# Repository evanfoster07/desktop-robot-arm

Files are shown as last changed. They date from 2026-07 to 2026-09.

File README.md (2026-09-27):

# Desktop Robot Arm

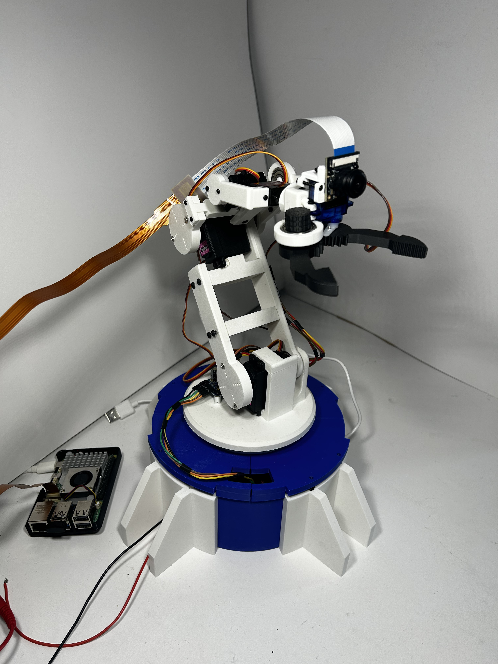
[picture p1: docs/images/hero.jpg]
Desktop Robot Arm


A 3D-printed desktop robot arm built from scratch, integrating robotics, embedded control, kinematics, and computer vision.

The arm is controlled by an ESP32 and uses a Raspberry Pi 5 with an eye-in-hand camera for computer vision. It combines custom motion control, forward/inverse kinematics, a custom-trained YOLO object detector, and closed-loop visual servoing to autonomously detect, approach, grasp, and place objects.

> Status: Object detection and arm control are integrated and working together to carry out autonomous pick-and-place tasks.

## Demo

Robot Arm Demo

*Autonomous pick-and-place demo with the robot’s POV shown above*

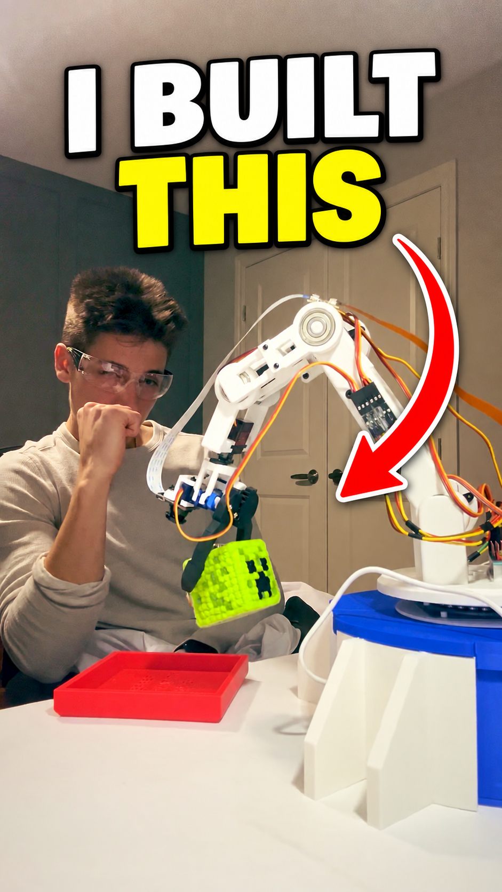
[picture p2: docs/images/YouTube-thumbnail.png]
Watch the full demo (https://youtube.com/shorts/6LVfA6hSM14?si=9LW-p4Ngw13JaFhd)


▶️ [Watch the full YouTube demo](https://youtube.com/shorts/6LVfA6hSM14?si=9LW-p4Ngw13JaFhd)

## Features

* Fully custom mechanical design in Fusion 360
* 3D-printed arm and gripper
* 5 controlled joints + gripper
* NEMA 17 stepper-driven base with TMC2209 control
* PCA9685-based servo control
* ESP32-based motion control
* Forward and inverse kinematics
* Cartesian end-effector positioning
* Non-blocking multi-joint servo motion
* Safe joint-angle limits and servo calibration
* Raspberry Pi 5 high-level control and computer vision
* Eye-in-hand IMX219 camera
* Custom YOLO object detection model
* Custom dataset captured from the robot's camera
* Raspberry Pi ↔ ESP32 serial communication
* Camera-space to robot-space coordinate transformation
* Closed-loop visual servoing with tunable Cartesian correction gains
* Autonomous target centering and approach
* Pitch retry logic for unreachable or unsuitable Cartesian poses
* Autonomous motion sequencing for grasping, goal alignment, placement, and return-home behavior
* Fully autonomous vision-guided pick and place

## Hardware

* ESP32 dev board
* Raspberry Pi 5 (8 GB)
* PCA9685 servo driver
* TMC2209 stepper motor driver
* NEMA 17 stepper motor
* MG996R servo x2
* 21G servo
* MG90S micro servo
* SG90 micro servo
* IMX219 camera
* 6V servo & stepper power supply
* Lazy Susan bearing
* 608 ball bearing x3
* Custom 3D-printed mechanical components
* Various fasteners and mounting hardware

## Mechanical Design

The arm was designed from scratch in Fusion 360 and went through a few iterations as I built and tested it.

The printable mechanical parts are available in [`main.3mf`](hardware/cad/main.3mf).

The base is driven by a NEMA 17 stepper motor, while the shoulder, elbow, wrist, and gripper are servo-driven. The final arm has control over:

1. Base rotation
2. Shoulder pitch
3. Elbow pitch
4. Wrist pitch
5. Wrist roll
6. Gripper

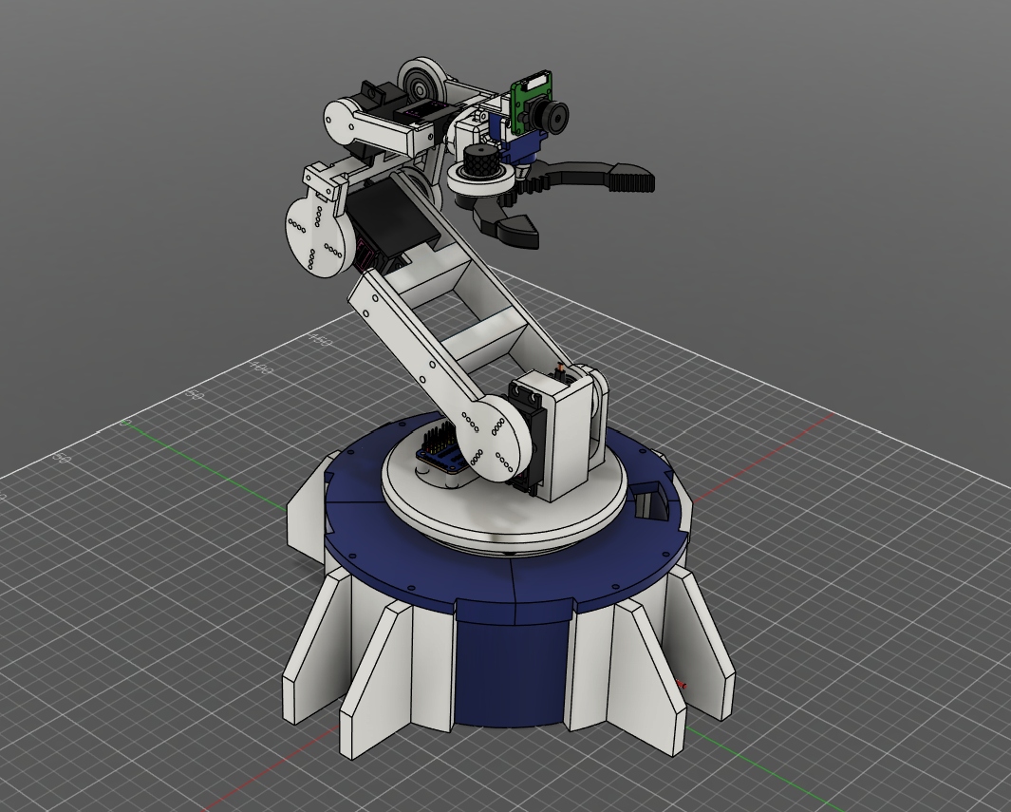
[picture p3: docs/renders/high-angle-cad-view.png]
High Angle CAD View


*High-angle CAD view of the complete robot arm assembly.*

A lot of the mechanical design ended up being driven by problems found during testing. For example, an early version of the base coupling had rotational slip, so I redesigned it with a tapered D-bore and external taper to improve repeatability. There was another issue where the wrist pitch servo screw did not adequately support the rest of the arm, so I designed a custom bracket to secure it in place.

Custom components include:

* Base and rotating platform
* Upper arm and forearm
* Wrist assembly
* Gripper
* Servo mounts
* Camera mount
* Electronics mounting components

## Electronics

The electronics are split between the ESP32 motion control system and the Raspberry Pi vision system.

The ESP32 controls the servos through the PCA9685 over I²C and configures the TMC2209 stepper driver over UART.

The main electronics include:

* ESP32 for real-time arm control
* PCA9685 for servo PWM control
* TMC2209 for NEMA 17 stepper control
* Dedicated 6V supply for the servos
* Raspberry Pi 5 for computer vision and high-level control
* IMX219 camera mounted to the arm

The system intentionally separates high-level perception and sequencing from low-level actuator control. The Raspberry Pi handles vision and task logic, while the ESP32 handles deterministic joint motion, calibration, and kinematics. 

- Raspberry Pi 5 communicates with the ESP32 over USB serial
- ESP32 receives Cartesian and joint commands
- ESP32 exposes current arm pose/state back to the Pi

The TMC2209 is configured through UART, allowing settings such as motor current and microstepping to be controlled in software.

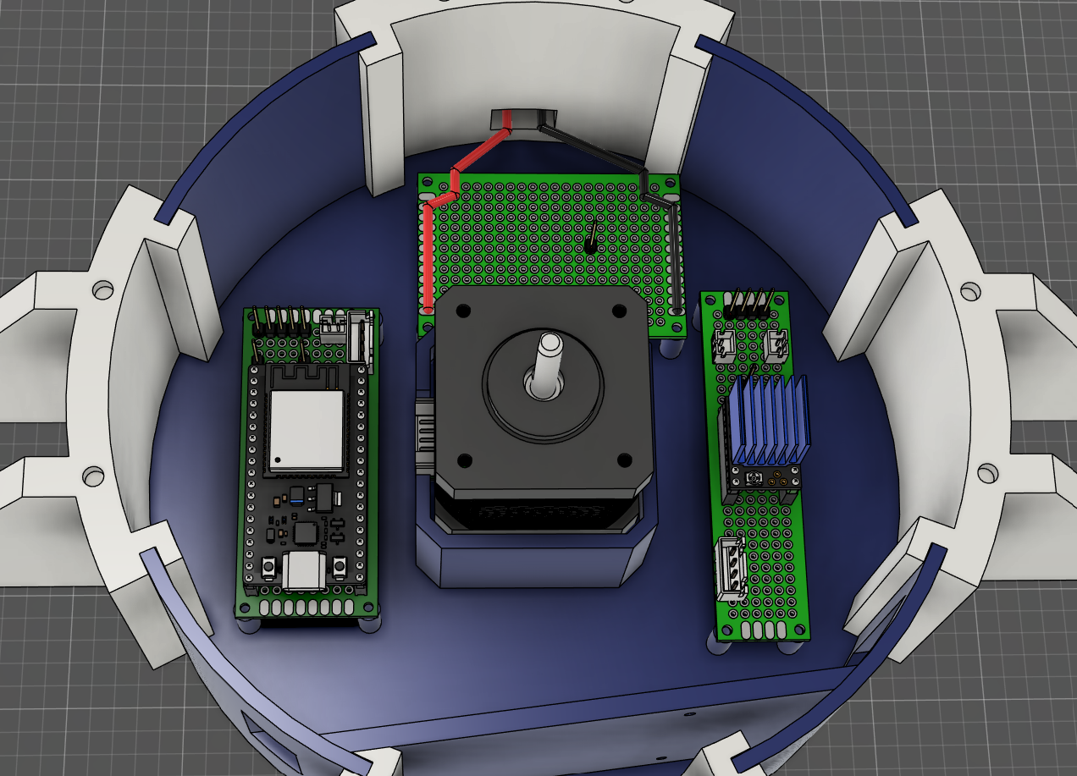
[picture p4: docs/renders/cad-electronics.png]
Base Electronics CAD


*CAD view of the electronics layout inside the robot arm base.*

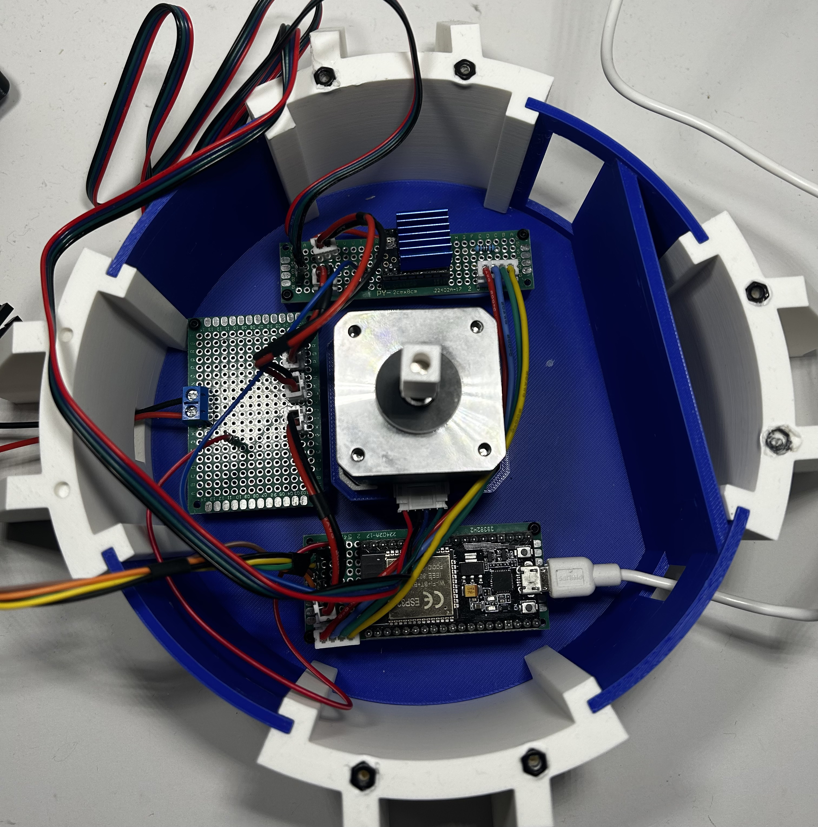
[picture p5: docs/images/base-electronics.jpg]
Base Electronics


*Final electronics implementation inside the robot base.*

The KiCad schematic and project files are available in [`kicad`](hardware/kicad/).

## Control System

The Raspberry Pi handles computer vision and higher-level decision making, while the ESP32 handles the actual motion of the arm.

The ESP32 firmware handles:

* Servo and stepper control
* Joint calibration
* Forward kinematics
* Inverse kinematics
* Cartesian pose commands
* Smooth multi-joint movement
* Safe joint limits
* Pose validation/rejection
* Servo pulse calibration
* Robot-state reporting over serial
* Joint-space and Cartesian command interfaces

### Motion Control

The arm can be controlled using either individual joint angles or Cartesian end-effector poses.

Forward kinematics calculate the end-effector position from the current joint angles, while inverse kinematics calculate the required joint angles for a desired position and orientation.

A calibration layer converts the mathematical joint angles into the actual servo coordinate system and accounts for servo direction, offsets, and mechanical limits.

Servo motion is also interpolated without blocking the main control loop, allowing multiple joints to move smoothly at the same time.

### Safety & Calibration

Each actuator has individually calibrated pulse-width and angular limits to prevent commands from driving the arm beyond its physical range. Cartesian poses are validated before execution, and the mapping layer converts mathematical joint angles into the physical coordinate system of each servo.

Custom classes were created for servo and stepper control, FK/IK, joint mapping, and higher-level robot arm control.

## Computer Vision

Computer vision runs on the Raspberry Pi 5 using an IMX219 camera mounted directly to the arm.

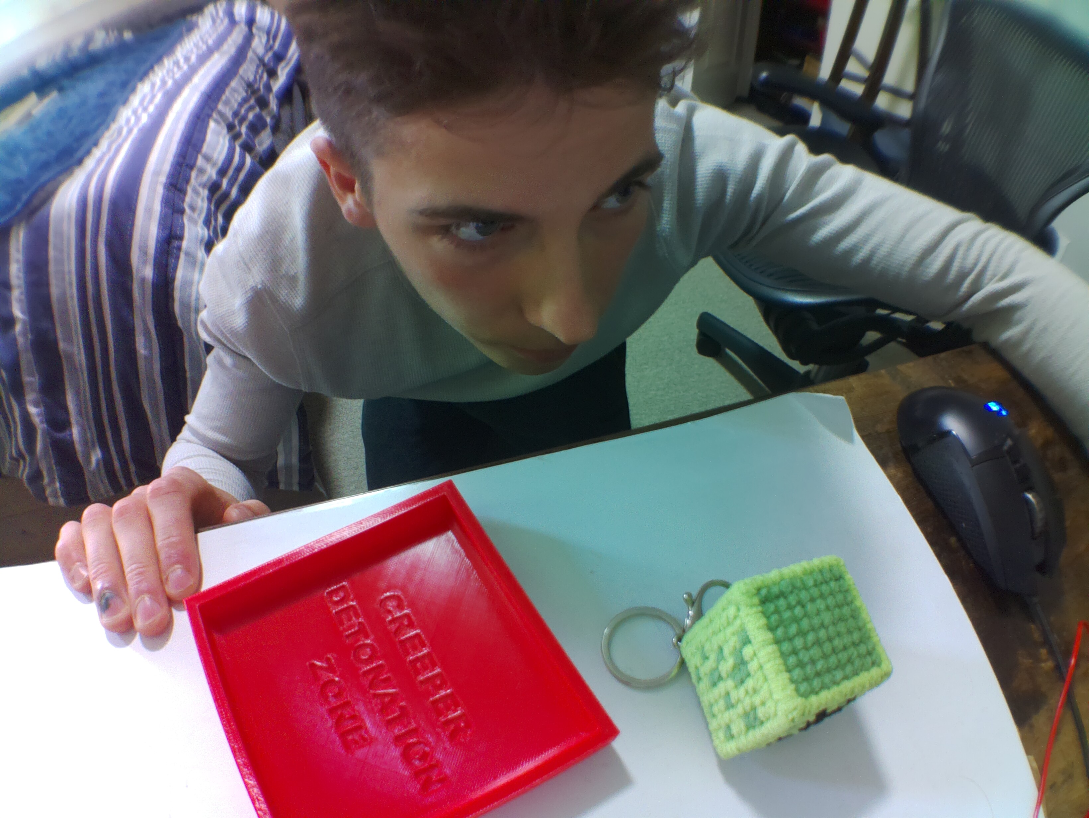
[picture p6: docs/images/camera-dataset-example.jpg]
Camera Dataset Example


*Example training image captured from the arm's eye-in-hand camera.*

I initially experimented with OpenCV ORB feature matching, but it wasn't reliable enough across different viewpoints. I then moved to a learned object detection approach using Ultralytics YOLO.

The current model is trained on a custom dataset of 625 images collected from the robot's own camera.

The training process includes:

* Custom Python dataset capture scripts using the eye-in-hand camera
* Annotation conversion tooling
* Transfer learning from pretrained YOLO weights
* Manual training-parameter tuning, including layer freezing and training duration
* Custom multi-class detection for the Creeper and goal
* Deployment to the Raspberry Pi for live inference

Training was performed using transfer learning rather than training a detector from scratch. I experimented with layer freezing, epoch count, batch size, and train/validation splits to balance training time and model performance before deploying the resulting weights to the Raspberry Pi.

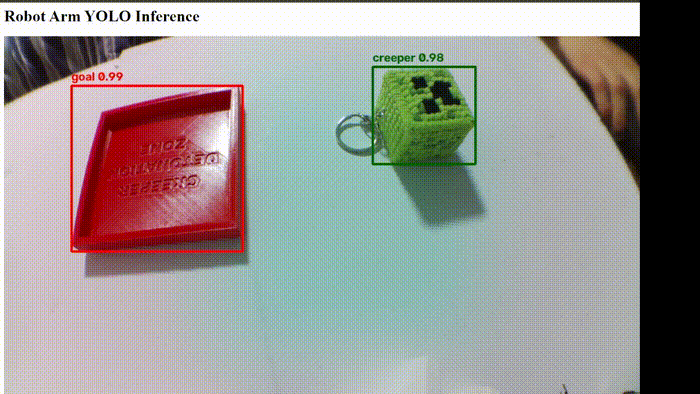
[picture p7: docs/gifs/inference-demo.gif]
YOLO Inference Demo


*Example inference using the custom-trained YOLO model.*

## Visual Servoing & Autonomous Pick and Place

Instead of relying on a precisely calibrated external camera or a single position estimate, I chose an eye-in-hand visual-servoing approach. This allowed me to use a low-cost camera mounted directly to the arm and continuously correct the robot's position using live image feedback.

The visual servoing process is:

1. Detect Creeper using the YOLO model
2. Calculate bounding-box error relative to the desired camera target
3. Normalize image-space error
4. Apply tunable Cartesian gains
5. Transform the correction from camera coordinates into the robot coordinate frame
6. Request the current Cartesian arm pose from the ESP32
7. Send the corrected Cartesian pose
8. Repeat until the target is centered
9. Execute autonomous approach and grasp
10. Return to start pose
11. Detect and center on the goal
12. Move to placement pose and release
13. Return home

Because some desired Cartesian corrections could produce unreachable or mechanically unsafe configurations, the high-level motion sequence includes retry logic that adjusts the end-effector pitch before attempting the pose again.

## Software

* C++ - ESP32 firmware, actuator control, calibration, forward/inverse kinematics, Cartesian motion, and safety limits
* Python - computer vision, YOLO training, visual servoing, motion sequencing, serial communication, dataset tools, and web interface
* Fusion 360 - mechanical design
* OpenCV - image processing and early CV experiments
* Ultralytics YOLO - object detection
* AccelStepper / TMCStepper - stepper control
* Adafruit PCA9685 - servo control

## Design Files

Project design files are included in the repository:

- [`hardware/cad/main.3mf`](hardware/cad/main.3mf) - 3D-printable robot arm parts
- [`hardware/kicad/`](hardware/kicad/) - KiCad schematic/project files for the robot electronics

## Development Process

The project has been developed and tested incrementally:

* Mechanical design and actuator integration
* Servo and stepper calibration
* Non-blocking motion control
* FK/IK and Cartesian control
* Raspberry Pi camera integration
* Custom YOLO dataset and training pipeline
* Pi ↔ ESP32 serial protocol
* Closed-loop visual servoing
* Autonomous motion sequencing
* Successful autonomous pick-and-place

## Challenges & Lessons Learned

* Mechanical repeatability:

  * Initial base coupling had significant rotational slip
  * Redesigned the coupling using a tapered D-bore and external taper
  * Added a custom wrist pitch bracket after identifying excessive movement around the servo mounting point

* Stepper control:

  * Configured the TMC2209 through UART
  * Tuned motor current, microstepping, speed, and acceleration
  * Debugged hardware and UART communication issues during integration

* Servo calibration:

  * Individually calibrated servo pulse-width ranges
  * Added mappings between mathematical joint angles and physical servo positions

* Kinematics:

  * Developed forward and inverse kinematics based on the arm's geometry
  * Worked through joint coordinate systems, offsets, and end-effector orientation
  * Validated calculated poses against the physical arm

* Computer vision:

  * Found traditional feature matching unreliable with changing camera viewpoints
  * Moved to a learned object detection approach using transfer learning
  * Collected a custom dataset from the robot's actual operating perspective

* Camera integration:

  * Integrated the camera into the moving arm while accounting for cable routing and joint movement
  * Built the image capture workflow directly around the Raspberry Pi camera

* Visual servoing:

  * Converted image-space bounding-box error into normalized Cartesian corrections
  * Tuned Cartesian gains and deadbands to reduce oscillation
  * Transformed camera-relative corrections into the robot frame using the arm's current orientation
  * Added retry logic for unreachable Cartesian poses
  * Learned that detection accuracy alone does not guarantee reliable manipulation

* System integration:

  * Designed a serial command protocol between Raspberry Pi and ESP32
  * Added robot-state queries so vision corrections could use the arm's current Cartesian pose
  * Built a motion state machine to coordinate centering, approach, grasp, goal alignment, placement, and return-home behavior

## Completed Milestones

* [x] Mechanical design and assembly
* [x] Individual joint control
* [x] Multi-joint motion
* [x] Stepper base control
* [x] Forward kinematics
* [x] Inverse kinematics
* [x] Cartesian pose commands
* [x] Eye-in-hand camera integration
* [x] Dataset capture and annotation pipeline
* [x] Custom YOLO object detection
* [x] Raspberry Pi inference
* [x] Raspberry Pi ↔ ESP32 communication
* [x] Vision-based position correction
* [x] Closed-loop visual servoing
* [x] Autonomous grasping
* [x] Autonomous pick and place

## Possible Future Improvements

* Faster object detection / hardware acceleration
* Improved mechanical repeatability
* Better trajectory planning
* More generalized object classes
* Depth estimation or stereo vision
* Simulation / ROS integration

## Third-Party CAD Models / Credits

The following component models were sourced from the GrabCAD Community Library and used for CAD assembly/visualization purposes:

- [JST XH 2.5 Connector Family](https://grabcad.com/library/jst-xh-2-5-connector-family-1) - by PENNEL Patrice
- [JST PH2.0 B2B-PH-K-S](https://grabcad.com/library/jst-ph2-0-b2b-ph-k-s-1) - by Anton Mukhin
- [Raspberry Pi 5 Single Board Computer](https://grabcad.com/library/raspberry-pi-5-single-board-computer-1) - by Ian T.
- [TMC2209 Stepper Driver](https://grabcad.com/library/tmc2209-stepper-driver-1) - by Nelson Stoldt
- [Double-Sided FR-4 Perfboards w/ M2 Corners](https://grabcad.com/library/double-sided-fr-4-perfboards-w-m2-corners-1) - by Steven Irwin
- [PCB 5x7 Heart Rate](https://grabcad.com/library/pcb-5x7-heart-rate-1) - by Diogo Araujo
- [NEMA 17 17HD40 Stepper](https://grabcad.com/library/nema-17-17hd40-stepper-1) - by Long Nguyen
- [PCA9685](https://grabcad.com/library/pca9685-7) - by Sven Rindfleisch
- [DS1021 Colored Male Pin Header 100mil (2.54 mm) Collection](https://grabcad.com/library/ds1021-colored-male-pin-header-100mil-2-54mm-collection-1) - by Sig Elso
- [KF128 2.54 mm Pitch Terminal Block Family](https://grabcad.com/library/kf128-2-54mm-pitch-terminal-block-family-2-pin-to-16-pin-1) - by PENNEL Patrice
- [Female Headers – Single Row](https://grabcad.com/library/female-headers-single-row-1) - by Mart Berghs
- [ESP32-WROOM-32E Dev Kit, 40 Pins](https://grabcad.com/library/esp32-wroom-32e-dev-kit-40pins-1) - by Matteo

All third-party CAD models remain the property of their respective creators.

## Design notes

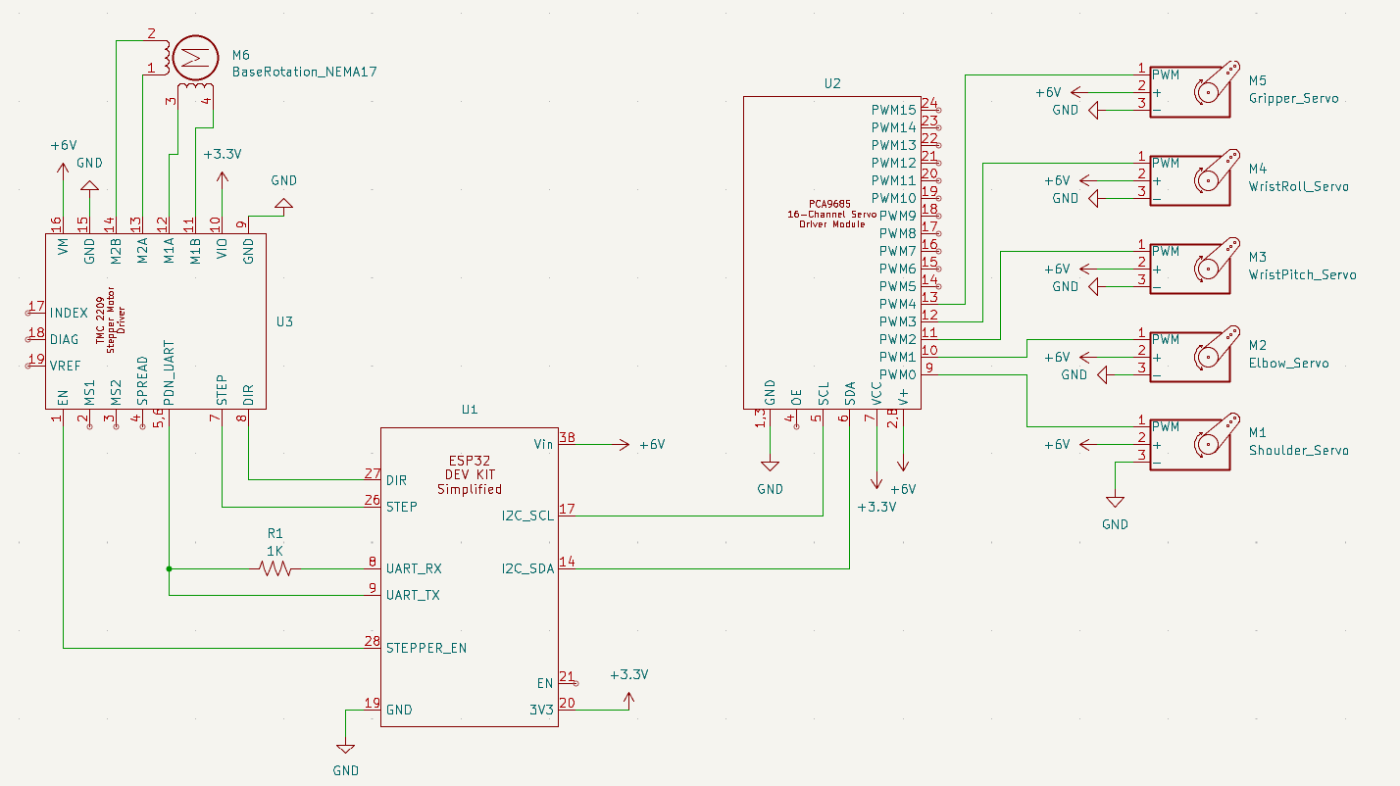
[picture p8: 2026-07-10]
docs/schematics/robot_arm_schematic.png

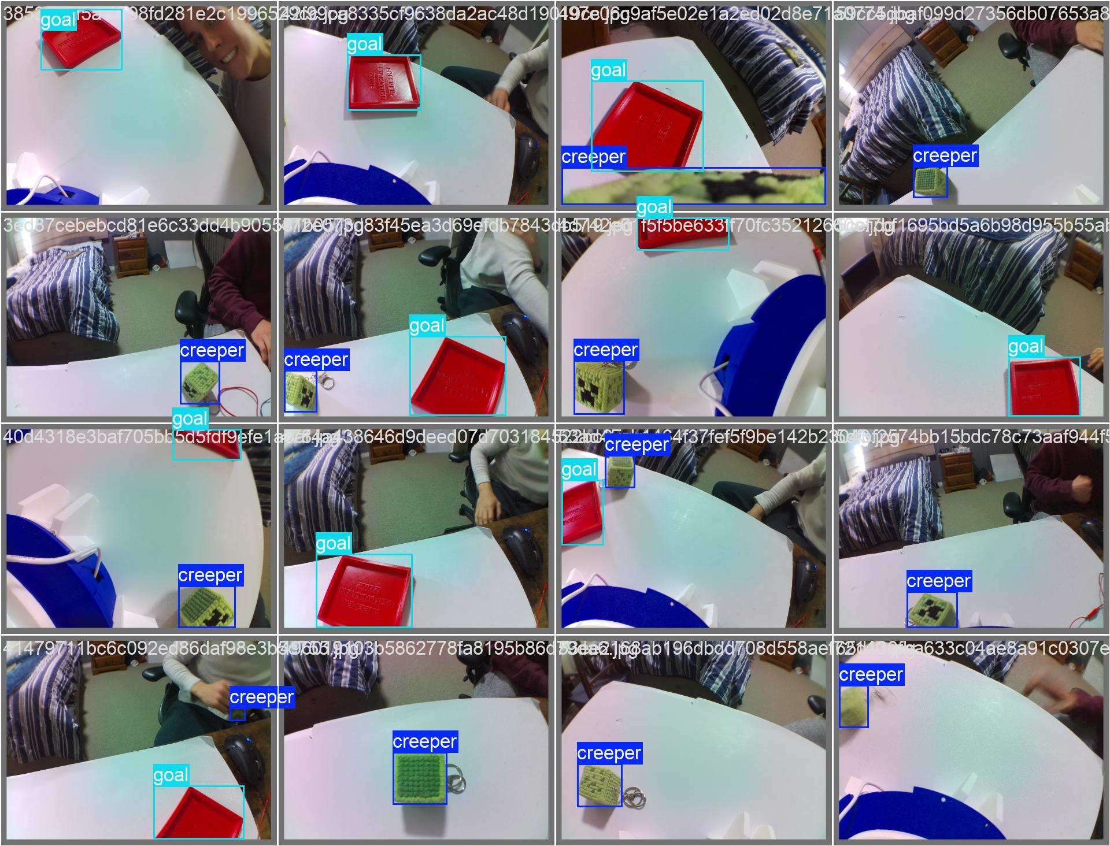
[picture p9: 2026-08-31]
src/raspberry-pi/src/vision/runs/detect/creeper-3/val_batch2_labels.jpg

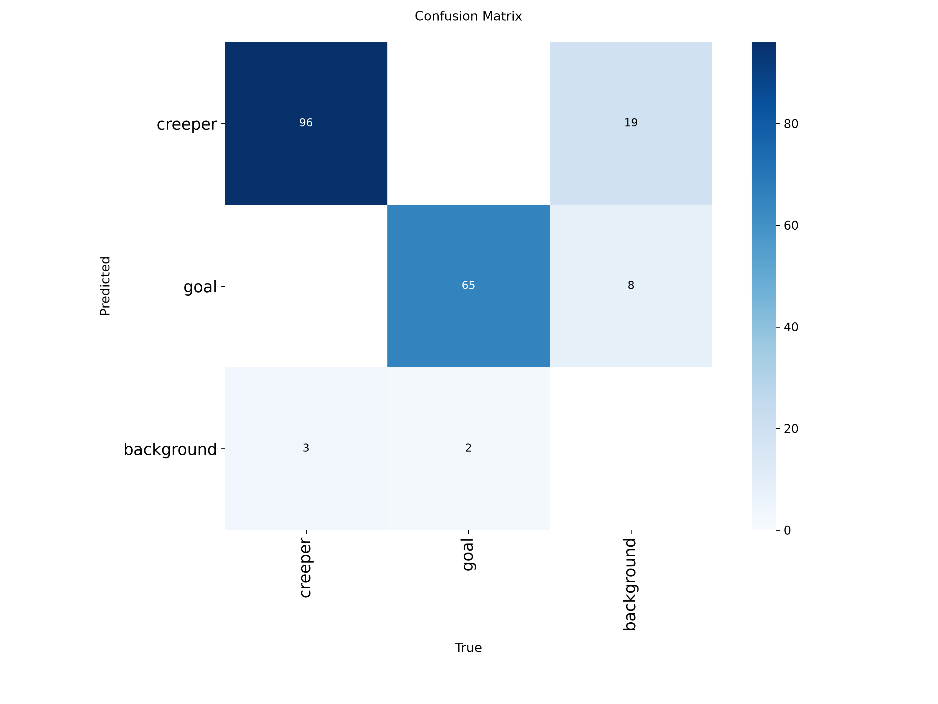
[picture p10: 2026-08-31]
src/raspberry-pi/src/vision/runs/detect/creeper-3/confusion_matrix.png

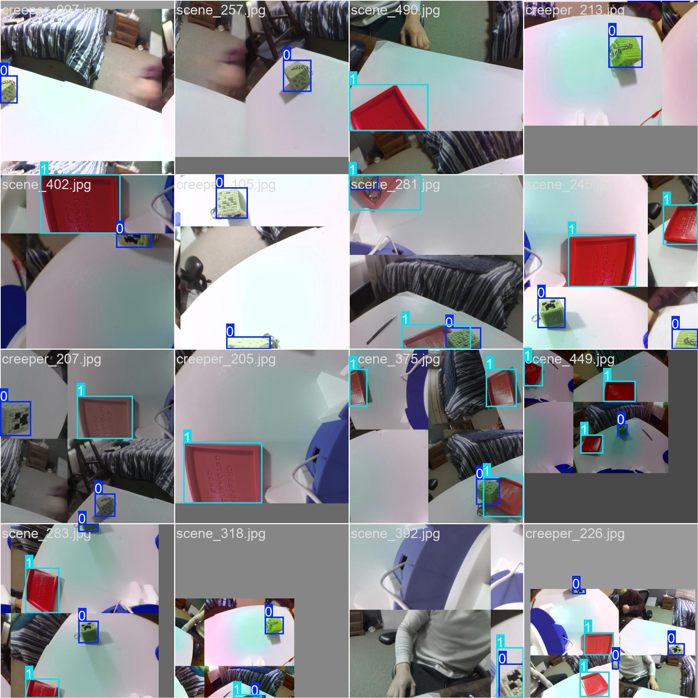
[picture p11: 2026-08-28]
src/raspberry-pi/src/vision/runs/detect/creeper-2/train_batch2.jpg

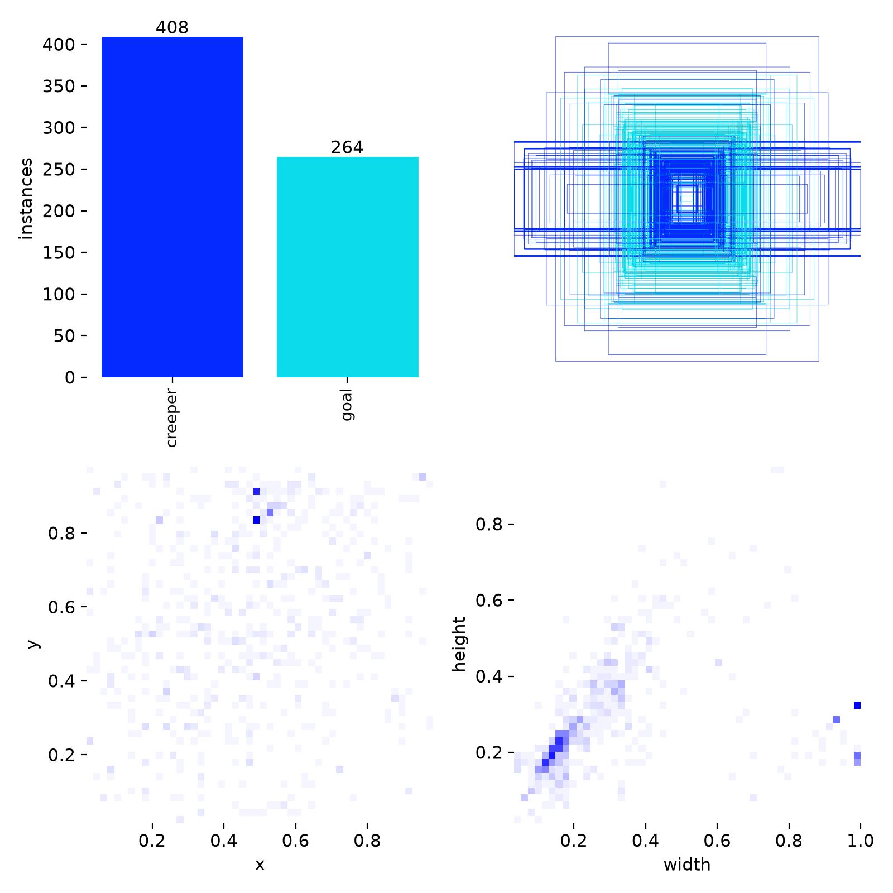
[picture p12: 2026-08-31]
src/raspberry-pi/src/vision/runs/detect/creeper-3/labels.jpg

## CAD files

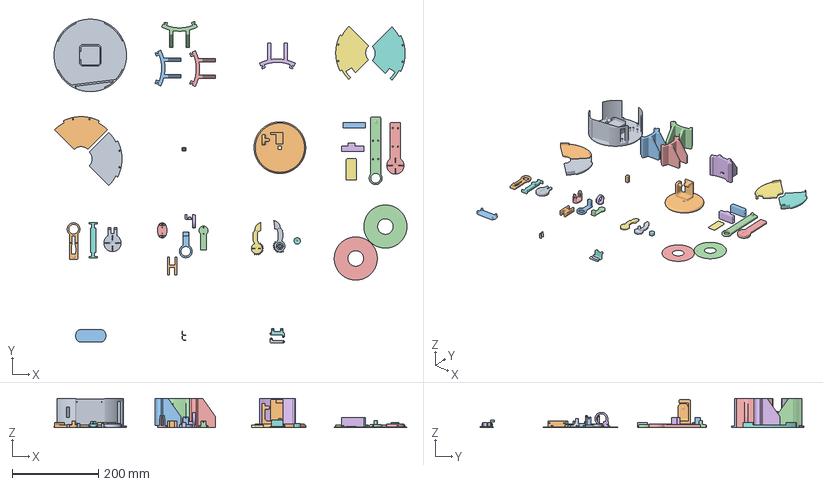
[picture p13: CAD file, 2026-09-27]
hardware/cad/print_files/main.3mf
817.5 x 749.8 x 68.0 mm
Base
Shoulder Mount
Base exterior (2)
Base exterior (1)
Base exterior (4)
Base exterior (3)
Base Top (1)
Base Top (2)
Base Top (3)
Base Top (4)
Upper Arm Support
Upper Arm Bearing Link
Upper Arm Servo Link
Upper Arm Servo Mount
Upper Arm Servo Support
Wrist Servo Support
Lower Servo Link
Lower Bearing Link
Wrist Bearing Link
Wrist Servo Link
Gripper Servo Support
Gripper Bearing Support
Gripper Servo Claw
Gripper Nut
Driven Gripper Claw
Wrist Pitch Servo Support
PCA9685 Mount
Lazy Susan Mount x 2
NEMA 17 Support x 2
Camera Mount Back
Camera Mount Front
Stepper Hub

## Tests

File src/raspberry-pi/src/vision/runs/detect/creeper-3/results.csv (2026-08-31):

epoch | time | train/box_loss | train/cls_loss | train/l1_loss | metrics/precision(B) | metrics/recall(B) | metrics/mAP50(B) | metrics/mAP50-95(B) | val/box_loss | val/cls_loss | val/l1_loss | lr/pg0 | lr/pg1 | lr/pg2
1 | 37.6389 | 0.5869 | 0.87737 | 0.00682 | 0.97465 | 0.79317 | 0.9148 | 0.85852 | 0.39376 | 0.7784 | 0.00593 | 0.000546847 | 0.000546847 | 0.000546847
2 | 52.7524 | 0.5722 | 0.73335 | 0.00644 | 0.92874 | 0.81765 | 0.96156 | 0.89467 | 0.41816 | 0.65344 | 0.00659 | 0.00104794 | 0.00104794 | 0.00104794
3 | 66.9057 | 0.61531 | 0.70885 | 0.00699 | 0.89699 | 0.87074 | 0.95666 | 0.86362 | 0.51551 | 0.5712 | 0.01041 | 0.00149402 | 0.00149402 | 0.00149402
4 | 81.2851 | 0.64663 | 0.70193 | 0.00708 | 0.86713 | 0.91459 | 0.95682 | 0.88116 | 0.44696 | 0.528 | 0.00624 | 0.00141945 | 0.00141945 | 0.00141945
5 | 95.4822 | 0.63241 | 0.59824 | 0.00678 | 0.86239 | 0.94754 | 0.96491 | 0.86872 | 0.50384 | 0.44048 | 0.00872 | 0.00133693 | 0.00133693 | 0.00133693
6 | 109.165 | 0.63243 | 0.56853 | 0.00681 | 0.87291 | 0.95236 | 0.96835 | 0.86854 | 0.50239 | 0.42258 | 0.00749 | 0.00125442 | 0.00125442 | 0.00125442
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

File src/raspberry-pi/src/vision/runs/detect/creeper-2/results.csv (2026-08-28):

epoch | time | train/box_loss | train/cls_loss | train/l1_loss | metrics/precision(B) | metrics/recall(B) | metrics/mAP50(B) | metrics/mAP50-95(B) | val/box_loss | val/cls_loss | val/l1_loss | lr/pg0 | lr/pg1 | lr/pg2
1 | 30.1442 | 0.58432 | 6.04121 | 0.00475 | 0.00489 | 0.97115 | 0.31084 | 0.29708 | 0.34768 | 7.93906 | 0.00375 | 0.000535086 | 0.000535086 | 0.000535086
2 | 36.2507 | 0.66401 | 4.70639 | 0.00575 | 0.0084 | 0.99038 | 0.71611 | 0.62434 | 0.52552 | 7.72719 | 0.0063 | 0.00105476 | 0.00105476 | 0.00105476
3 | 42.0525 | 0.68635 | 4.0846 | 0.00573 | 0.92848 | 0.30326 | 0.87683 | 0.75477 | 0.63994 | 6.74441 | 0.00881 | 0.00153776 | 0.00153776 | 0.00153776
4 | 47.8332 | 0.69962 | 3.45801 | 0.00579 | 0.87854 | 0.79782 | 0.92208 | 0.83908 | 0.47854 | 4.95873 | 0.00615 | 0.00150197 | 0.00150197 | 0.00150197
5 | 53.5774 | 0.71628 | 2.91631 | 0.00595 | 0.86674 | 0.82034 | 0.93327 | 0.82997 | 0.54206 | 4.05892 | 0.00656 | 0.00144696 | 0.00144696 | 0.00144696
6 | 59.3537 | 0.70578 | 2.61154 | 0.00579 | 0.89912 | 0.93109 | 0.96572 | 0.84718 | 0.56654 | 3.29986 | 0.00758 | 0.00139195 | 0.00139195 | 0.00139195
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

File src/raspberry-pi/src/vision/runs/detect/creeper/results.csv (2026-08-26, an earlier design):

epoch | time | train/box_loss | train/cls_loss | train/l1_loss | metrics/precision(B) | metrics/recall(B) | metrics/mAP50(B) | metrics/mAP50-95(B) | val/box_loss | val/cls_loss | val/l1_loss | lr/pg0 | lr/pg1 | lr/pg2
1 | 21.4865 | 0.66921 | 7.75875 | 0.00433 | 0.00104 | 0.31915 | 0.14088 | 0.11799 | 0.44593 | 9.72512 | 0.00331 | 0.000615385 | 0.000615385 | 0.000615385
2 | 24.8249 | 0.69228 | 6.17418 | 0.00429 | 0.00146 | 0.44681 | 0.11524 | 0.0914 | 0.67919 | 9.54239 | 0.00524 | 0.00121859 | 0.00121859 | 0.00121859
3 | 28.1576 | 0.82403 | 5.65033 | 0.00565 | 0.00049 | 0.14894 | 0.00018 | 0.0001 | 0.54753 | 9.27308 | 0.00408 | 0.00175579 | 0.00175579 | 0.00175579
4 | 31.2648 | 0.7494 | 5.16679 | 0.00508 | 0.00278 | 0.85106 | 0.32276 | 0.25632 | 0.60842 | 8.62022 | 0.00434 | 0.001703 | 0.001703 | 0.001703
5 | 34.4151 | 0.79013 | 4.86015 | 0.00541 | 0.00319 | 0.97872 | 0.7574 | 0.63503 | 0.60944 | 7.9917 | 0.00478 | 0.001604 | 0.001604 | 0.001604
6 | 37.7631 | 0.63259 | 4.3438 | 0.00468 | 0.28091 | 0.95745 | 0.83088 | 0.73745 | 0.57737 | 7.46571 | 0.00418 | 0.001505 | 0.001505 | 0.001505
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

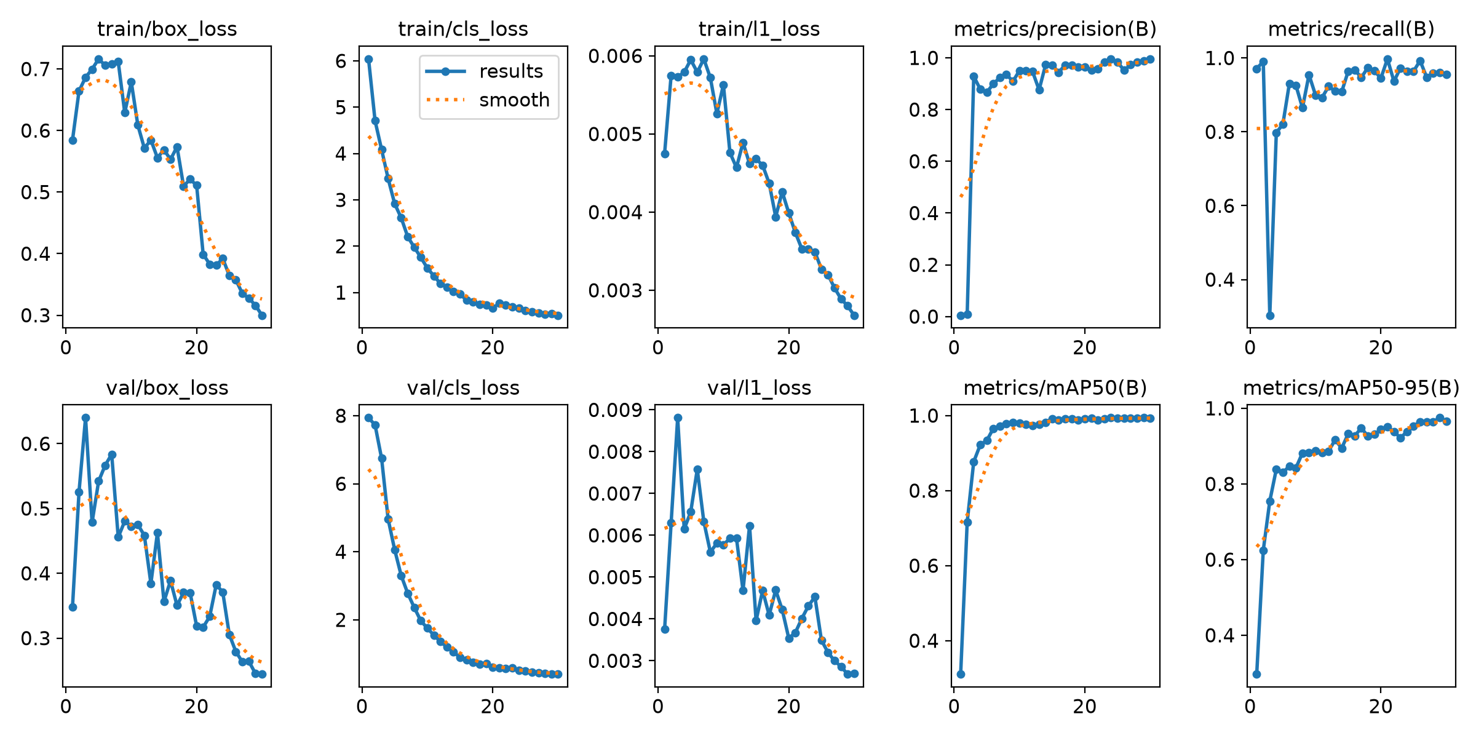
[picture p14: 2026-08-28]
src/raspberry-pi/src/vision/runs/detect/creeper-2/results.png

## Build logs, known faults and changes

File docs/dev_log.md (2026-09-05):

## June 9 -> June 23 2026
- Modelled and 3D-printed the following: 
    - Base frame 
    - Upper & lower arm link and pitch joints 
    - Wrist link and pitch joint 
    - Wrist roll joint
    - Gripper open/close mechanism
- Assembled main components and servos
- Tested all servo function and ensured sufficient shoulder torque for full 180° ROM
- Created code to test the control of each servo angle individually and tested combined rotation sequences

## June 25 2026
- Tested PCA9685 servo driver using Adafruit servo driver library examples
- Configured PCA9685 and calibrated min/max pulse width values for accurate positioning
- Designed, 3D-printed and added a clamp to the arm to stabilize wrist pitch servo

## June 27 2026
- Designed, 3D-printed and attached mount for PCA9685 servo driver

- Next: attach M-F jumper wires to lower arm for wrist roll + gripper servo wire extension 

## June 29 2026
- Attached M-F jumper wires to extend wrist roll + gripper servo wire connections
- Tested PCA9685 servo driver and servo function with new mount + wire extensions

- Next: 
    - Set up TMC2209 stepper motor driver and test base rotation 
    - Start electrical schematic and begin planning internal component placement

## June 30 2026
- Began electrical schematic and created custom symbols for ESP32, TMC2209, and PCA9685
- Started wiring TMC2209 stepper motor driver to test base rotation & driver control 

- Next:
    - Finish electrical schematic
    - Write TMC2209 control code and test stepper motor base rotation

## July 1 2026
- Finished wiring TMC2209 stepper motor driver and tested with control code

- Next:
    - Finish electrical schematic
    - Begin planning internal wire pathing, component locations on perfboards, and communication/power terminal locations

## July 2 2026
- Finished electrical schematic primary power rails/distribution & communication connections 
- Began planning electrical component and connector placements in Fusion 360 assembly model
- Issue: creep in lazy susan bearing mounts where pegs can no longer hold arm upright at far extents, leading to the arm detaching
    - Will fix with custom threaded pegs and nuts to secure in place

- Next:
    - Continue planning component/connector placements for internal wiring
    - Print and attach new lazy Susan mounts and test at max arm extent to verify mount stability at maximum torque

## July 4 2026
- Finished planning component/connector placements 
- Organized components on perfboards to prepare for soldering 

- Next: 
    - Solder components and wire connections on perfboards 
    - Crimp signal/power wires with JST XH connectors and shrink wrap together for organization

## July 6 2026
- cut, organized and crimped with JST XH connectors the required wires for internal power/signal connections

- Next:
    - Begin soldering header pins onto perfboard 
    - Solder wire connections between header pins on perfboard 

## July 8 2026
- Completed soldering all female/male dupont header pins, JST XH female connectors, and power screw terminals onto perfboards
- Began soldering 6V and GND power rails and routed to JST XH female pins for power distribution
- Tested solder joints and performed continuity tests on completed perfboard connections

- Next: 
    - Continue soldering wire connections on perfboard

## July 10 2026
- Finished soldering wire connections for both servo driver and stepper driver communication lines and power on perfboards
- Continuity tested all connections and ensured common ground between all components
- Verified no short circuits were present in wiring

- Next:
    - Attach finished perfboards to base of arm and verify function with test code
    - Begin writing integrated control code for stepper & servo motors

## July 11 2026
- Mounted all perfboards to base of arm and attached all JST/Dupont cables 
- Performed continuity testing between all major components' pins and checked for short circuits

- Next: 
    - Begin writing integrated control code for all motor control

## July 14 2026
- Began writing main servo & stepper control code
- Implemented the following:
    - Base rotation control using AccelStepper
    - TMC2209 configuration via UART communication using TMCStepper library
    - PC -> ESP32 Serial commands for testing & controlling motors
- Successfully tested bidirectional base rotation through serial commands

- Next:
    - Configure and test PCA9685 communication over I2C
    - Implement servo control commands for all arm joints
    - Expand serial interface to support individual joint angle commands

## July 15 2026
- Continued development of main servo & stepper control code
- Implemented the following:
    - Servo angle control via Serial commands 
    - `ServoJoint` struct + array architecture for individual servo data organization and accessibility. Includes:
        - Per-servo pulse calibration
        - State tracking
        - Home angles 
    - Improved Serial command parsing to allow testing, calibration and servo/base rotation angle/step selection

- Next:
    - Finish per-servo calibration values using pulse selection Serial commands
    - Fully assemble arm and attempt object manipulation using manual joint position control

## July 16 2026
- Finished per-servo pulse width calibration and implemented as constant values in code 
- Tested object manipulation via manual servo control

- Issue: NEMA 17 stepper motor rotates slightly in base frame during direction changes
    - Fix: secure NEMA 17 using custom 3D printed inserts

- Next:
    - Design & print inserts to secure NEMA 17 stepper motor
    - Begin writing class for inverse/forward kinematics
    - Refactor motor control logic into separate .h and .cpp files

## July 17 2026 
- Refactored motor control and command logic into separate .h and .cpp files 
- Designed and printed inserts to secure NEMA 17 stepper motor
- Tested motor control using refactored code and calibrated arm home position

- Next:
    - Begin writing classes for inverse/forward kinematics
    - Add individual speed control for all servo joints via non-blocking timing logic

## July 18 2026
- Implemented non-blocking per-servo interpolation with configurable movement speeds and continuous state-based servo updates
- Added optional per-servo interpolation, allowing individual joints to move either smoothly or instantly

- Next: 
    - Begin implementing forward kinematics to calculate the end-effector position from joint angles
    - Define arm's link lengths and joint rotation directions in code

## July 19 2026 
- Implemented initial forward kinematics architecture:
    - Created shared kinematics data structures for robot geometry, joint angles, and Cartesian poses
    - Built ForwardKinematics class to calculate gripper pose from joint angles

- Next:
    - Implement inverse kinematics
    - Verify forwards kinematics accuracy with pose calculations from given joint angles

## July 22 2026
- Completed Fusion 360 CAD assembly to verify joint angles & positions for inverse/forward kinematics

- Next:
    - Implement inverse kinematics
    - Verify forwards/inverse kinematics with CAD model and by replicating physical positions
    
## July 24 2026
- Implemented IK math in InverseKinematics class and verified calculations between FK/IK
- Refactored robot arm control into RobotArmControl class:
    - Contains high-level control responsibilities
    - Central class for initialization and update logic
    - Improved organization to prepare for joint mapping and cartesian motion
    - No functional behaviour changes

- Next:
    - Map mathematical IK angles to raw servo command angles
    - Verify raw servo command angle mapping is accurate by testing various cartesian poses

## July 25 2026 
- Finished mapping math IK angles to raw servo commands with JointMapper class and per-servo calibration
- Added unmap() function to reverse mapping operation so FK can be used to obtain cartesian poses from JointAngles
- Implemented poses.h to store cartesian poses for the arm to achieve through serial commands
- Issue:
    - Unmapped physical servo angles give reasonable FK estimate, but when the output cartesian pose is commanded,
    some are calculated as unreachable under servo constraints 
    - Possible fix: 
        - verify constraints are accurate and code from physical angles -> mathematical angles -> FK -> cartesian pose to verify proper calculations
        - Add tolerance to safe servo angles to allow rounding/floating-point differences between FK/IK to achieve similar poses

- Next: 
    - Verify kinematics calculations & test if tolerance fixes pose issue

## July 26 2026
- Traced FK/IK calculations and realized cartestian pose command issue was caused because only the positive IK elbow angle branch is considered
    - Fixed by adding a negative branch calculation in IK, and selecting branch in calculateBestActuatorTargets() most similar to current arm pose

- Next:
    - Test commands for all predefined grab poses in cartesian form

## July 27 2026
- Tested and verified function for all grab pose commands in cartesian form
- Carried out test pick-and-place tasks with various objects and pre-defined cartesian poses

- Next:
    - Learn about integrating a Raspberry Pi 5 + camera for object recognition
    - Script short demo video for current state of project, showcasing:
        - FK/IK
        - Pick-and-place tasks
        - Dev process so far
        - Kinematics math

## July 28 2026
- Issue: Found that UART TX/RX pins were connected to the wrong TMC2209 pin, meaning UART configuration was not being applied
    - Fix: re-solder ESP32 -> TMC2209 UART wires onto proper pins

## === BREAK (trip) ===

## August 16 2026
- Fixed UART RX/TX pin connection issue and verified UART communication
- Tested various microstepping and RMS current settings as well as driver modes

- Issue: NEMA17 coupler slips under arm load approximately 22° (200 microsteps = approx 22°)
    - Fix: tighten coupling shaft tolerance and re-print part

## August 17 2026
- Tightened CAD tolerance for NEMA17 -> base coupler, then re-printed and attached finished part
- Designed, printed and attached Raspberry pi camera mount + module to arm

- Issue: tested new motor hub, however slip is still present for ~4° of rotation 
    - Fix: re-design hub with tapered D-bore to minimize slip

- Next: print and attach new NEMA17 hub and begin planning CV implementation with R+aspberry pi 

## August 18 2026
- Re-designed, then printed and attached NEMA17 motor hub with internal tapered D-bore and external taper for tighter base-platform coupling
    - Reduced overall slip to ~0.2° from ~22° after testing (2 microsteps slip = approx 0.2°)
- Configured and tested Raspberry pi SSH for CV development

- Next:
    - Begin CV development on Pi
    - Establish Pi -> ESP32 communication via Serial USB connection

## August 20 2026
- Began CV testing with OpenCV ORB feature detection
    - Successfully detected and matched features between reference and scene images
    - Homography-based object localization was unreliable, particularly with changes in viewing angle
    - Decided to move toward CNN-based object detection using transfer learning
    
- Next:
    - Begin planning CNN code architecture
    - Obtain & label training images from robot perspective before camera extension arrives

## August 22 2026
- Began YOLO object detection implementation
    - Installed Ultralytics YOLO and PyTorch on Raspberry Pi
    - Loaded pretrained YOLO26n model
    - Integrated OpenCV image loading with YOLO inference
    - Successfully detected objects from test images
        - Tested detection on target creeper keychain object

- Next:
    - Create custom creeper keychain dataset
    - Label training images with bounding boxes

## August 23 2026
- Implemented custom YOLO object detection pipeline
    - Created and annotated creeper dataset
    - Created Python script to convert Ultralytics NDJSON annotations to YOLO train/val format
    - Tested fine-tuning of pretrained YOLO26n model on Raspberry Pi
    - Evaluated model using precision, recall, mAP, and loss
    - Initial model showed poor generalization due to very limited training data

- Next:
    - Expand dataset
    - Train same dataset on laptop with frozen early layers to compare performance
    - Integrate Pi camera with OpenCV inference

## August 24 2026
- Moved YOLO training from Raspberry Pi to laptop for significantly faster training
- Retrained test creeper detection model on laptop for 20 epochs
- Tested trained model on new images and training set images
    - For new images: extremely low confidence, excessive detections
    - Training set images: higher but still low confidence, more reliable detections
    
- Next:
    - Continue collecting diverse training images with Raspberry Pi camera
    - Improve dataset/model performance before deploying inference to Raspberry Pi

## August 25 2026
- Integrated IMX219 eye-in-hand camera with Raspberry Pi 5
    - Connected camera using extended CSI ribbon cable setup for arm mobility
    - Diagnosed camera detection and ribbon connection issues
    - Configured IMX219 device tree overlay for camera detection
- Verified camera is successfully detected by Raspberry Pi

- Next:
    - Develop automated image capture and naming script
    - Collect robot-perspective images for YOLO dataset
    - Label images and retrain object detection model

## August 26 2026
- Expanded Creeper detection dataset to 243 robot-camera images
- Updated NDJSON conversion script to support negative/background images with no annotations
- Retrained YOLO model using transfer learning on laptop
    - Achieved ~0.96 mAP50 and ~0.90 mAP50-95 on validation set
    - Successfully detected Creeper in various robot-camera images
- Added Raspberry Pi camera dataset capture script

- Next:
    - Deploy new `best.pt` model to Raspberry Pi to test camera inference
    - Collect and label images of second `goal` object class
    - Retrain as two-class Creeper/goal detector

## August 27 2026
- Implemented live Raspberry Pi camera streaming to browser
- Implemented real-time YOLO inference on live robot camera feed
    - Streams annotated detections with bounding boxes and confidence
    - Extracts bounding box coordinates and target center for future control
    - Achieved reliable Creeper detection
- Designed and printed 100 x 100 mm goal tray for autonomous pick-and-place

- Next:
    - Capture and label goal object dataset
    - Retrain YOLO with Creeper and goal classes
    - Begin integrating vision detections with robot control

## August 28 2026
- Expanded CV dataset with images of new `goal` object
- Updated dataset for multi-class detection
- Retrained YOLO model on expanded dataset
- Retrained YOLO model for multi-class `creeper` and `goal` detection. Best epoch:
  - Validation mAP50: 0.994
  - Validation mAP50-95: 0.975
  - Precision: 0.989
  - Recall: 0.960
  
- Next:
  - Test new model on live Raspberry Pi camera feed
  - Begin integrating vision output with arm control

## August 29, 2026
- Added `tracking.py` to begin closed-loop visual tracking.
- Implemented functions to calculate detected object centers and pixel error relative to the camera target point
- Added horizontal and vertical correction logic using a configurable deadzone
- Tested tracking calculations using hard-coded bounding boxes and confirmed expected directions

- Next:
    - Implement Pi <-> ESP32 communication to retrieve the arm's current joint/orientation state
    - Use the current arm state with visual tracking error to determine and apply movement corrections
    - Begin closed-loop visual centering

## August 30 2026
- Implemented Pi <-> ESP32 serial communication for visual tracking control
- Added commands to retrieve the arm's current Cartesian pose and orientation from the ESP32
- Implemented camera-space -> robot-space transformation using the current base angle and tool pitch
- Integrated visual tracking corrections with Cartesian arm control
    - Calculates robot XYZ corrections from normalized bounding box error
    - Added configurable deadband, correction gain, and maximum movement clamps
    - Tracks only the highest-confidence Creeper detection to prevent multiple commands from one frame
- Improved serial communication reliability
- Implemented continuous closed-loop visual servoing
- Refactored tracking control to prevent the browser camera stream from freezing
    - Moved ESP32 state requests and movement commands onto a background control thread
    - Prevented new corrections from being queued while the previous serial operation is still running
    - Added background error reporting and removed continuous detection printing
- Successfully tested continuous base and wrist tracking

- Next:
    - Capture close-up and partially cropped Creeper images from the arm camera
    - Retrain the model for reliable detection at grabbing distance
    - Implement incremental forward approach using normalized bounding-box size as the stopping condition
    - Add approach and grabbing motion sequencing

## August 31 2026
- Refactored live inference to integrate the full autonomous pick-and-place sequence
    - Added browser controls for starting/stopping autonomous motion
    - Added browser input for sending manual ESP32 serial commands
- Expanded visual tracking for autonomous approaching
    - Added configurable target points and normalized bounding-box size metrics
    - Switched vertical tracking corrections from pitch changes to Cartesian camera movement
- Improved Pi <-> ESP32 motion handling
    - Added pose acceptance/failure handling
    - Added motion settling checks before issuing new corrections
    - Added recovery attempts using smaller Cartesian moves and nearby pitch targets
- Implemented autonomous pick-and-place state machine
    - Centers and approaches the Creeper
    - Grabs and returns to the viewing pose
    - Detects and approaches the goal
    - Drops the Creeper and retreats
- Successfully completed first autonomous pick-and-place test
- Added terminal grab logic for close-range pickup
    - Switches from visual servoing to a calibrated final forward lurch before the Creeper leaves the camera view
    - Added relative wrist pitch adjustment before closing the gripper

- Next:
    - Improve grab sequence and visual servoing smoothness and speed
    - Test grab sequence with various initial object locations 

## September 1 2026
- Tuned final lurch for more reliable Creeper pickup
- Tested autonomous pickup from varied initial object positions
- Began scripting and editing final demo video

- Next:
    - Finish editing demo video
    - Update README.md with state of finished project

## September 2 - September 5 2026 
- Finished final demo video
- Polished README.md
    - Added successful pick-and-place demo gif with robot POV
    - Updated project status and documented new features
    - Elaborated on design process and added new challenged I faced

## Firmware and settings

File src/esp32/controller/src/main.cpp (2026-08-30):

#include <Arduino.h>

#include "Config.h"
#include "RobotArmControl.h"
#include "SerialCommandHandler.h"

RobotArmControl robotArm{
    KinematicsConfig::ARM_GEOMETRY,
    JointMappingConfig::SHOULDER_CALIBRATION,
    JointMappingConfig::ELBOW_CALIBRATION,
    JointMappingConfig::WRIST_PITCH_CALIBRATION,
    JointMappingConfig::BASE_STEPS_PER_DEGREE
};

void setup()
{
    Serial.begin(115200);

    robotArm.begin();
    beginSerialCommands(robotArm);

    Serial.println("Robot arm controller ready");

}

void loop()
{
    readSerialCommands();
    robotArm.update();
}

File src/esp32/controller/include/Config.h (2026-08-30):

#pragma once

#include "KinematicsData.h"
#include <Arduino.h>

namespace Pins {
    
    //Servo I2C pins
    constexpr int SCL_PIN = 22;
    constexpr int SDA_PIN = 21;

    //TMC2209 & Stepper control pins
    constexpr int STEPPER_EN = 25;
    constexpr int UART_RX = 16;
    constexpr int UART_TX = 17;
    constexpr int STEP_PIN = 32;
    constexpr int DIR_PIN = 33;
}

namespace StepperConfig {

    //TMC2209 sense resistor value
    constexpr float R_SENSE = 0.11f;

    //TMC2209 UART address
    constexpr uint8_t DRIVER_ADDRESS = 0;
    constexpr uint32_t UART_BAUD_RATE = 115200;

    //TMC2209 config
    constexpr uint16_t RMS_CURRENT_MA = 800;
    constexpr uint16_t MICROSTEPS = 16;

    constexpr float MAX_SPEED = 800.0f;
    constexpr float ACCELERATION = 1000.0f;
}

namespace ServoConfig {

    //PCA9685 address & PWM frequency
    constexpr uint8_t PCA9685_ADDRESS = 0x40;
    constexpr int PWM_FREQUENCY = 50;     // 50 Hz
}

//  Geometry config (mm)
namespace KinematicsConfig {
    constexpr ArmGeometry ARM_GEOMETRY
    {
        130.0f,     // Base bottom to shoulder axis height
        130.0f,     // Shoulder to elbow 
        63.0f,      // Elbow to wrist pitch 
        120.0f      // Wrist pitch to gripper reference
    };
}

namespace JointMappingConfig
{
    constexpr JointCalibration SHOULDER_CALIBRATION
    {
        90.0f,   // Mathematical reference angle
        90.0f,   // Servo angle at reference
        1.0f     // Direction
    };

    constexpr JointCalibration ELBOW_CALIBRATION
    {
        0.0f,
        90.0f,
        1.0f
    };

    constexpr JointCalibration WRIST_PITCH_CALIBRATION
    {
        0.0f,
        90.0f,
        1.0f
    };

    constexpr float BASE_STEPS_PER_DEGREE = 3200.0f / 360.0f;   // Total steps per rev / 360 deg
}

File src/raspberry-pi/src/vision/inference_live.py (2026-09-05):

import cv2
from flask import Flask, Response, redirect, render_template, request, url_for
from libcamera import Transform
from picamera2 import Picamera2
from ultralytics import YOLO

from arm_serial import ArmSerial
from motion_sequence import MotionSequence, SequenceConfig


MODEL_PATH = "src/vision/runs/detect/creeper-3/weights/best.pt"
FRAME_SIZE = (1280, 720)
INFERENCE_SIZE = 640

CLASS_COLORS = {
    0: (0, 100, 0),
    1: (0, 0, 255),
}

SEQUENCE_CONFIG = SequenceConfig(
    gripper_open_angle=40,
    gripper_closed_angle=60,
    creeper_grab_width_norm=0.65,
    final_grab_forward_mm=14,
    final_grab_wrist_pitch_delta_deg=10,
    goal_drop_width_norm=0.65,
    approach_sign=1.0,
)


app = Flask(__name__)
model = YOLO(MODEL_PATH)
arm = ArmSerial()
sequence = MotionSequence(arm, SEQUENCE_CONFIG)

last_manual_command = ""
last_manual_response = ""


# Camera setup
picam2 = Picamera2()
camera_config = picam2.create_video_configuration(
    main={"size": FRAME_SIZE},
    raw={"size": picam2.sensor_resolution},
    transform=Transform(hflip=1, vflip=1),
)
picam2.configure(camera_config)
picam2.start()


def get_detections(frame):
    result = model(frame, imgsz=INFERENCE_SIZE, verbose=False)[0]
    detections = []

    for box in result.boxes:
        x1, y1, x2, y2 = box.xyxy[0].tolist()
        detections.append({
            "class_id": int(box.cls[0]),
            "confidence": float(box.conf[0]),
            "box": [x1, y1, x2, y2],
            "center": [(x1 + x2) / 2, (y1 + y2) / 2],
        })

    return detections


def draw_detections(frame, detections):
    annotated = frame.copy()

    for detection in detections:
        class_id = detection["class_id"]
        confidence = detection["confidence"]
        x1, y1, x2, y2 = map(int, detection["box"])
        color = CLASS_COLORS.get(class_id, (255, 255, 255))
        label = f"{model.names[class_id]} {confidence:.2f}"

        cv2.rectangle(annotated, (x1, y1), (x2, y2), color, 3)
        _draw_text(
            annotated,
            label,
            (x1, max(y1 - 10, 20)),
            0.8,
            color,
        )

    return annotated


def draw_sequence_debug(frame):
    debug = sequence.get_debug_info()
    _draw_text(frame, f"STATE: {debug['state']}", (20, 35), 0.8)

    if debug["target_point"] is not None:
        tx, ty = map(int, debug["target_point"])
        cv2.drawMarker(
            frame,
            (tx, ty),
            (255, 255, 255),
            cv2.MARKER_CROSS,
            24,
            2,
        )

    y = 65
    metrics = debug["target_metrics"]
    error_norm = debug["error_norm"]

    if metrics is not None:
        _draw_text(
            frame,
            f"target width={metrics['width_norm']:.3f} "
            f"area={metrics['area_norm']:.3f}",
            (20, y),
        )
        y += 28

    if error_norm is not None:
        _draw_text(
            frame,
            f"error=({error_norm[0]:.3f}, {error_norm[1]:.3f})",
            (20, y),
        )
        y += 28

    if debug["moving"]:
        _draw_text(frame, "ARM MOVING", (20, y))

    return frame


def run_inference(frame):
    detections = get_detections(frame)
    sequence.update(detections, frame.shape[1], frame.shape[0])

    annotated = draw_detections(frame, detections)
    draw_sequence_debug(annotated)
    return annotated, detections


def generate_frames():
    while True:
        frame = picam2.capture_array()
        frame = cv2.cvtColor(frame, cv2.COLOR_RGB2BGR)
        annotated, _ = run_inference(frame)

        success, buffer = cv2.imencode(".jpg", annotated)
        if not success:
            continue

        yield (
            b"--frame\r\n"
            b"Content-Type: image/jpeg\r\n\r\n"
            + buffer.tobytes()
            + b"\r\n"
        )


def _draw_text(
    frame,
    text,
    position,
    scale=0.65,
    color=(255, 255, 255),
):
    cv2.putText(
        frame,
        text,
        position,
        cv2.FONT_HERSHEY_SIMPLEX,
        scale,
        color,
        2,
    )


@app.route("/")
def index():
    return render_template(
        "index.html",
        state=sequence.get_debug_info()["state"],
        last_command=last_manual_command,
        last_response=last_manual_response,
    )


@app.route("/command", methods=["POST"])
def manual_command():
    global last_manual_command, last_manual_response

    command = request.form.get("command", "").strip()
    if not command:
        return redirect(url_for("index"))

    last_manual_command = command

    if sequence.active:
        last_manual_response = (
            "Command blocked: stop the autonomous sequence first."
        )
        return redirect(url_for("index"))

    try:
        response_lines = arm.run_command(command)
        last_manual_response = (
            "\n".join(response_lines)
            if response_lines
            else "Command sent (no serial response)."
        )
    except Exception as exc:
        last_manual_response = f"Serial command error: {exc}"

    return redirect(url_for("index"))


@app.route("/start", methods=["POST"])
def start_sequence():
    sequence.start()
    return redirect(url_for("index"))


@app.route("/stop", methods=["POST"])
def stop_sequence():
    sequence.stop()
    return redirect(url_for("index"))


@app.route("/video_feed")
def video_feed():
    return Response(
        generate_frames(),
        mimetype="multipart/x-mixed-replace; boundary=frame",
    )


if __name__ == "__main__":
    app.run(
        host="0.0.0.0",
        port=5000,
        debug=False,
        threaded=True,
    )

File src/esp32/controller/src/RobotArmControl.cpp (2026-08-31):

#include "RobotArmControl.h"

#include "StepperController.h"

RobotArmControl::RobotArmControl(
    const ArmGeometry& geometry,
    const JointCalibration& shoulderCalibration,
    const JointCalibration& elbowCalibration,
    const JointCalibration& wristPitchCalibration,
    float baseStepsPerDegree
)
    : forwardKinematics(geometry),
      inverseKinematics(geometry),
      jointMapper(
          shoulderCalibration,
          elbowCalibration,
          wristPitchCalibration,
          baseStepsPerDegree
      )
{
}

void RobotArmControl::begin()
{
    beginServos();
    beginStepper();
}

void RobotArmControl::update()
{
    updateStepper();
    updateServos();
}

void RobotArmControl::setServoAngle(ServoId servoId, int requestedAngle)
{
    ::setServoAngle(servoId, requestedAngle);
}

void RobotArmControl::writeServoPulse(ServoId servoId, int pulseWidthUS)
{
    ::writeServoPulse(servoId, pulseWidthUS);
}

void RobotArmControl::homeServos()
{
    ::homeServos();
}

void RobotArmControl::moveBase(long relativeSteps)
{
    ::moveBase(relativeSteps);
}

void RobotArmControl::stopBase()
{
    ::stopBase();
}

long RobotArmControl::getBasePosition() const
{
    return ::getBasePosition();
}

bool RobotArmControl::solveInverseKinematics(const CartesianPose& target, JointAngles& solution) const
{
    JointAngles positiveBranch;
    JointAngles negativeBranch;

    const bool positiveReachable = inverseKinematics.solve(target, positiveBranch, true);
    const bool negativeReachable = inverseKinematics.solve(target, negativeBranch, false);

    if (!positiveReachable && !negativeReachable)
    {
        return false;
    }

    if (positiveReachable && !negativeReachable)
    {
        solution = positiveBranch;
        return true;
    }

    if (!positiveReachable && negativeReachable)
    {
        solution = negativeBranch;
        return true;
    }

    const JointAngles referenceJoints = getCurrentJointAngles();

    const float positiveScore =
        (positiveBranch.shoulder - referenceJoints.shoulder) * (positiveBranch.shoulder - referenceJoints.shoulder) +
        (positiveBranch.elbow - referenceJoints.elbow) * (positiveBranch.elbow - referenceJoints.elbow) +
        (positiveBranch.wristPitch - referenceJoints.wristPitch) * (positiveBranch.wristPitch - referenceJoints.wristPitch);

    const float negativeScore =
        (negativeBranch.shoulder - referenceJoints.shoulder) * (negativeBranch.shoulder - referenceJoints.shoulder) +
        (negativeBranch.elbow - referenceJoints.elbow) * (negativeBranch.elbow - referenceJoints.elbow) +
        (negativeBranch.wristPitch - referenceJoints.wristPitch) * (negativeBranch.wristPitch - referenceJoints.wristPitch);

    solution = (positiveScore <= negativeScore) ? positiveBranch : negativeBranch;

    return true;
}

CartesianPose RobotArmControl::solveForwardKinematics(const JointAngles& joints) const
{
    return forwardKinematics.solve(joints);
}

JointAngles RobotArmControl::getCurrentJointAngles() const
{
    /*
        ServoController tracks physical servo angles. JointMapper expects
        those physical values in ActuatorTargets so it can reverse the
        calibration offsets and direction signs.
    */
    ActuatorTargets currentTargets;

    currentTargets.baseSteps = getBasePosition();
    currentTargets.shoulderServoAngle =
        getServoJoint(ServoId::Shoulder).currAngle;
    currentTargets.elbowServoAngle =
        getServoJoint(ServoId::Elbow).currAngle;
    currentTargets.wristPitchServoAngle =
        getServoJoint(ServoId::WristPitch).currAngle;

    JointAngles joints = jointMapper.unmap(currentTargets);

    /*
        Wrist roll is currently not mapped by JointMapper because it is
        not used by the planar IK calculation. Its servo angle directly
        represents the reported roll for now.
    */
    joints.wristRoll = getServoJoint(ServoId::WristRoll).currAngle;

    return joints;
}


CartesianPose RobotArmControl::getCurrentPose() const
{
    /*
        ForwardKinematics must receive mathematical joint angles, not
        raw servo angles. getCurrentJointAngles() performs that reverse
        conversion first.
    */
    return forwardKinematics.solve(getCurrentJointAngles());
}

bool RobotArmControl::calculateActuatorTargets(const CartesianPose& target, ActuatorTargets& actuatorTargets) const 
{
    const JointAngles referenceJoints = getCurrentJointAngles();
    JointAngles jointAngles;

    return calculateBestActuatorTargets(target, referenceJoints, jointAngles, actuatorTargets);
}


bool RobotArmControl::calculateActuatorTargets(
    const CartesianPose& target,
    const JointAngles& referenceJoints,
    JointAngles& solution,
    ActuatorTargets& actuatorTargets
) const
{
    return calculateBestActuatorTargets(target, referenceJoints, solution, actuatorTargets);
}


bool RobotArmControl::calculateBestActuatorTargets(
    const CartesianPose& target,
    const JointAngles& referenceJoints,
    JointAngles& solution,
    ActuatorTargets& actuatorTargets
) const
{
    JointAngles positiveBranch;
    JointAngles negativeBranch;
    ActuatorTargets positiveTargets;
    ActuatorTargets negativeTargets;

    const bool positiveReachable = inverseKinematics.solve(target, positiveBranch, true);
    const bool negativeReachable = inverseKinematics.solve(target, negativeBranch, false);

    if (!positiveReachable && !negativeReachable)
    {
        return false;
    }

    const bool positiveValid = positiveReachable && jointMapper.map(positiveBranch, positiveTargets);
    const bool negativeValid = negativeReachable && jointMapper.map(negativeBranch, negativeTargets);

    if (!positiveValid && !negativeValid)
    {
        return false;
    }

    // Compare 'score' of each branch for best option
    const float positiveScore =
        (positiveBranch.shoulder - referenceJoints.shoulder) * (positiveBranch.shoulder - referenceJoints.shoulder) +
        (positiveBranch.elbow - referenceJoints.elbow) * (positiveBranch.elbow - referenceJoints.elbow) +
        (positiveBranch.wristPitch - referenceJoints.wristPitch) * (positiveBranch.wristPitch - referenceJoints.wristPitch);

    const float negativeScore =
        (negativeBranch.shoulder - referenceJoints.shoulder) * (negativeBranch.shoulder - referenceJoints.shoulder) +
        (negativeBranch.elbow - referenceJoints.elbow) * (negativeBranch.elbow - referenceJoints.elbow) +
        (negativeBranch.wristPitch - referenceJoints.wristPitch) * (negativeBranch.wristPitch - referenceJoints.wristPitch);

    if (positiveValid && (!negativeValid || positiveScore <= negativeScore))
    {
        solution = positiveBranch;
        actuatorTargets = positiveTargets;
        return true;
    }

    solution = negativeBranch;
    actuatorTargets = negativeTargets;
    return true;
}
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

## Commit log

2026-06-15 add platformIO project to repo and verify shoulder servo function with simple test code
2026-06-29 test: verify servo function with PCA9685 driver and configure min/max pulses
    -
2026-07-14 feat: add basic TMC2209 and serial command framework
    - Configure TMC2209 over UART
    - Add AccelStepper integration
    - Add serial command parser
    - Implement basic movement commands for testing
2026-07-15 feat: implement structured servo control and serial calibration commands
    - Add ServoJoint struct and joint configuration array
    - Track per-servo channel, angle limits, pulse limits, home angle, and current angle
    - Add safe servo angle control with angle constraints and pulse mapping
    - Update serial parsing to support command-value input
    - Add direct pulse commands for individual servo calibration
    - Add serial control for relative base stepper movement
    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
2026-07-16 feat: calibrate individual servo pulse widths
2026-07-17 refactor: improve Serial command handling and refactor servo, stepper, and serial control into separate modules
    - Move shared constants into Config.h
    - Add dedicated controller headers and source files
    - Keep main.cpp focused on setup and loop coordination
    - Encapsulate hardware objects within their modules
2026-07-18 feat: implement non-blocking, configurable servo movement interpolation
    - Added optional non-blocking servo interpolation using per-servo target positions
    - Implemented configurable movement speeds for each servo
    - Introduced continuous servo updates
2026-07-19 feat: implement forward kinematics framework
    - Added the ForwardKinematics class for calculating gripper poses from joint angles
    - Created shared kinematics data structures for robot geometry, joint angles, and Cartesian poses
2026-07-24 feat: implement inverse kinematics solver
    - Added inverse kinematics for the robot arm
    - Compute base, shoulder, elbow, and wrist pitch from Cartesian targets
    - Added reachability checks and floating-point tolerance handling
    - Verified IK by comparing solutions against forward kinematics
2026-07-24 refactor: create RobotArmControl class for control logic
    - Created RobotArmControl class to coordinate robot subsystems
    - Moved high-level control responsibilities out of main.cpp
    - Improved project organization to prepare for joint mapping and Cartesian motion
2026-07-26 feat: add joint mapping and preset pose control
    - Introduces a JointMapper layer to convert IK joint angles into calibrated actuator commands, validate mapped servo limits, and reverse-map current hardware positions back into mathematical joints for FK.
    - RobotArmControl now supports mapped pose moves, current-pose reporting, and actuator-target calculation/printing. Also adds predefined Cartesian poses plus new serial commands: `fk` for current FK output and `pose <index>` for moving to saved poses.
    [Config.h, JointMapper.cpp, RobotArmControl.cpp]
2026-07-26 fix: calculate and choose safest IK branch by joint proximity
    - Added dual-branch inverse kinematics support by letting IK solve either elbow-positive or elbow-negative solutions.
    - RobotArmControl now evaluates both branches, filters by actuator-limit validity, and selects the reachable/safe solution closest to a reference joint state.
    [RobotArmControl.cpp]
2026-08-19 feat: add initial Raspberry Pi CV setup
2026-08-25 feat: update YOLO training and add retrained model run
    [results.csv]
2026-08-26 feat: train YOLO model on new set of 243 images from robot POV
    [results.csv]
2026-08-27 feat: implement Python script for live browser robot camera inference using trained YOLO model
2026-08-28 feat: add goal dataset and retrain YOLO for creeper and goal detection
    [results.csv]
2026-08-28 feat: re-train two-class model with proper test/val split
    [results.csv]
2026-08-29 feat: implement web robot camera display for capturing data
2026-08-29 feat: implement foundational functions for robot camera centering and correction
    [tracking.py]
2026-08-30 test: add camera calibration testing poses
2026-08-30 feat: print TMC config on boot for UART debugging
2026-08-30 feat: add serial commands for arm state and Cartesian pose control
2026-08-30 feat: implement necessary Pi <-> ESP32 state correction communication via Serial
    [arm_serial.py]
2026-08-30 feat: integrate visual tracking corrections with live arm pose and Cartesian control
    [inference_live.py]
2026-08-30 change correction deadband to 0.2
    [tracking.py]
2026-08-30 fix: improve serial reliability
    [arm_serial.py]
2026-08-30 feat: implement continuous visual servoing with non-blocking arm control
2026-08-31 feat: switch to image url download from .ndjson
2026-08-31 add creeper-3 training run with new close-up images
    [results.csv]
2026-08-31 feat: add camera-frame transforms and target metrics for visual servoing
2026-08-31 feat: add motion settling, pose failure handling, and manual serial command support
    [arm_serial.py]
2026-08-31 feat: implement relative wrist pitch angle commands for Raspberry Pi final grab
2026-09-07 docs: add attribution for CAD electronics models
2026-09-27 docs: add KiCad schematic files
    [desktop_robot_arm.kicad_sch]
2026-09-27 docs: add .3mf print file for entire arm
    [main.3mf]
